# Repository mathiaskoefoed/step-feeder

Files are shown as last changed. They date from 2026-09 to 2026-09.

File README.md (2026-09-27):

# Step Feeder - ESP32 Aquarium Feeder
An ESP32-based automatic aquarium feeder built around the auger screw and food container salvaged from a Juwel SmartFeed 2.0, running on [ESPHome](https://esphome.io/) with full Home Assistant Integration.

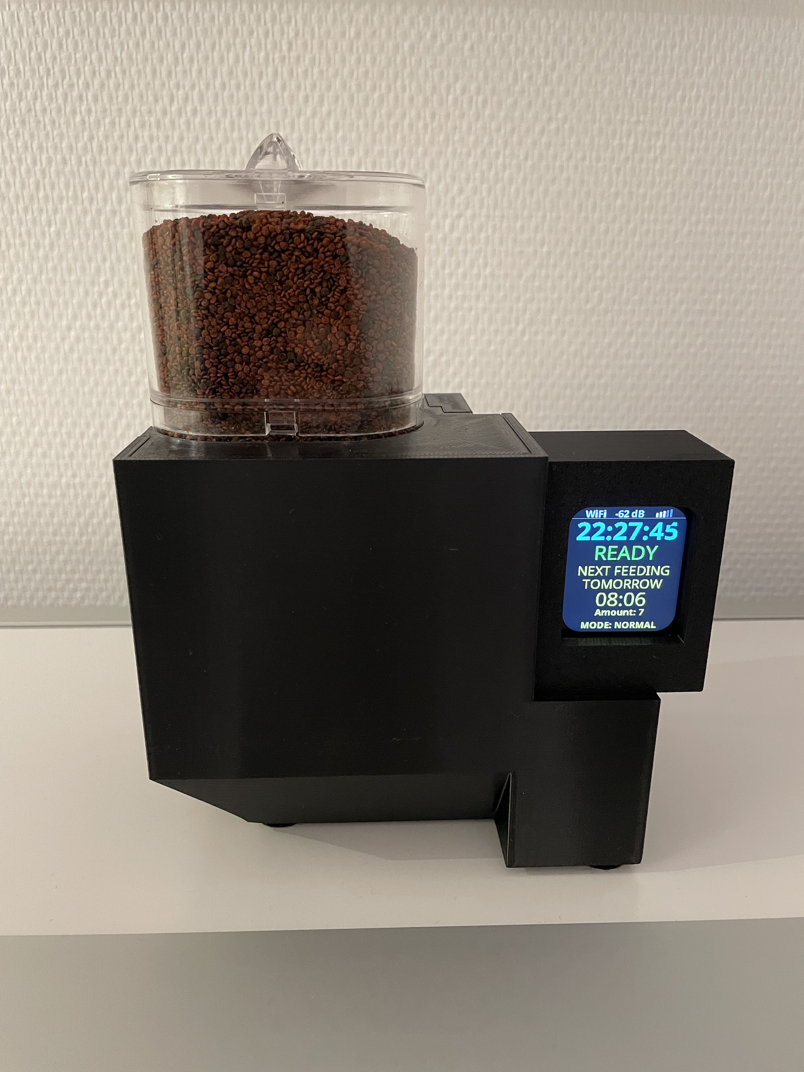
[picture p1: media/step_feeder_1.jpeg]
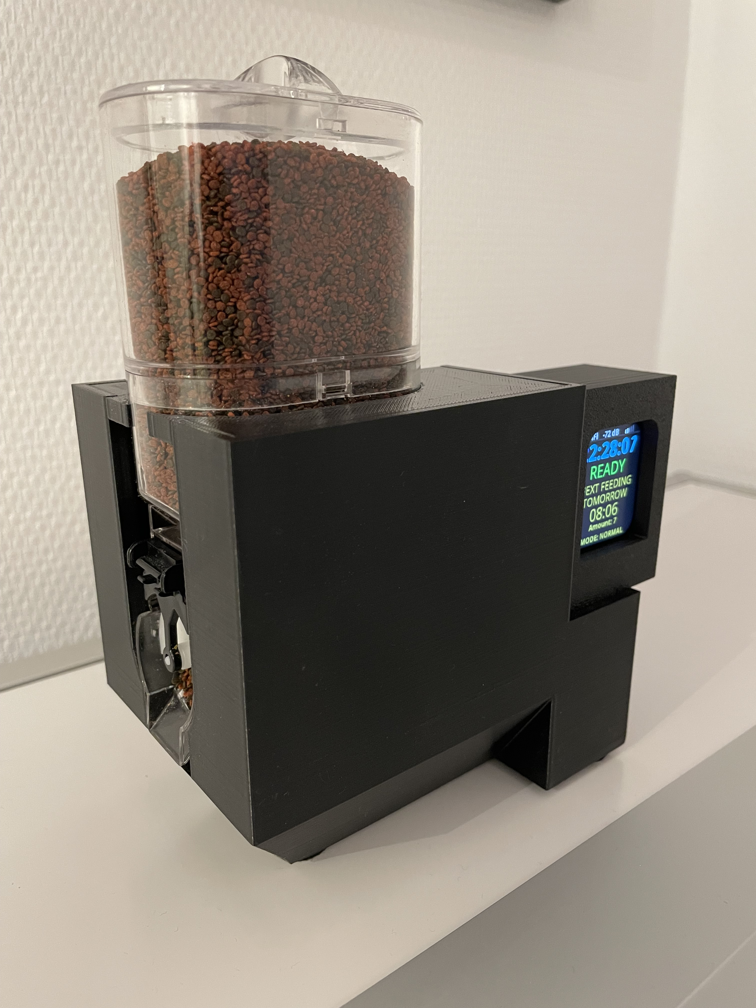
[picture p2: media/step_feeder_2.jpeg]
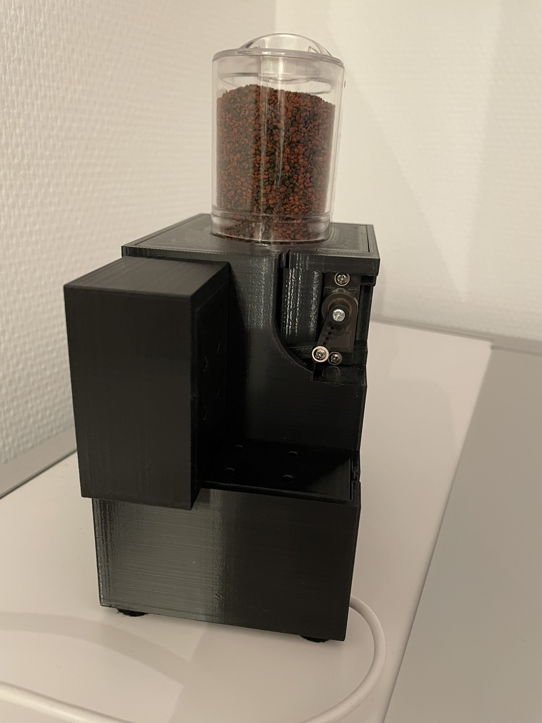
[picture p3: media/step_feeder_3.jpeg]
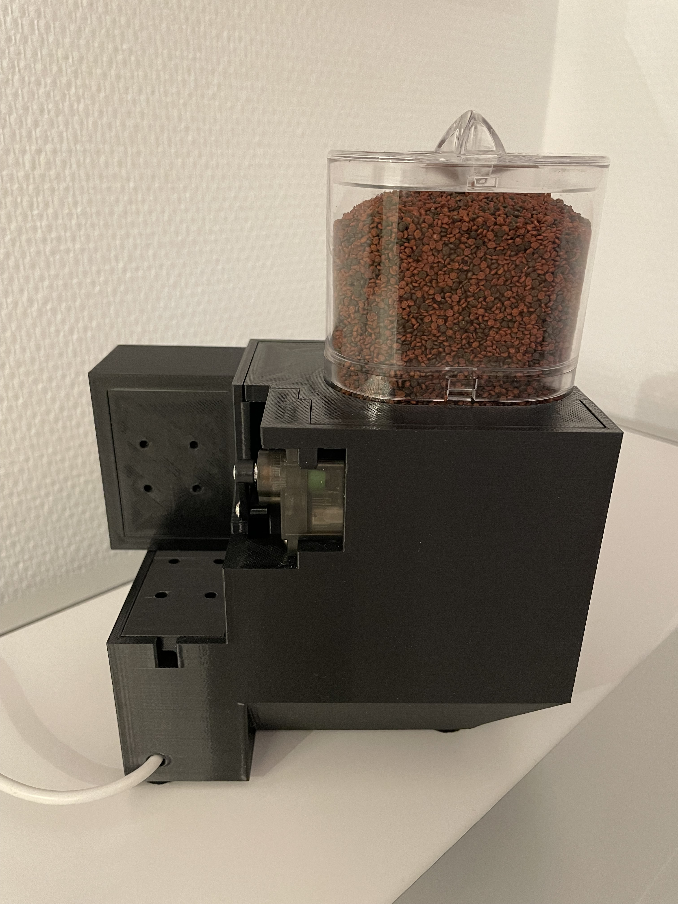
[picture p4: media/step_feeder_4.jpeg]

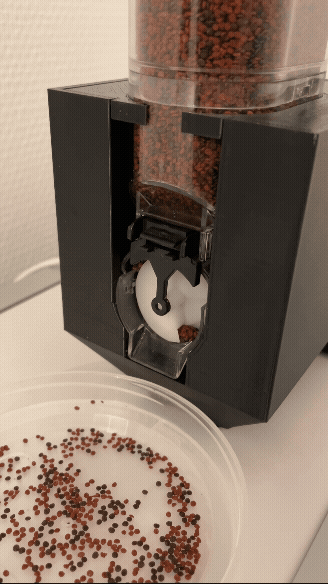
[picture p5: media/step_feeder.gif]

## Table of Contents
- [Features](#features)
- [Add-ons](#add-ons)
- [Hardware](#hardware)
- [Prerequisites](#prerequisites)
- [Build steps](#build-steps)
- [Calibration](#calibration)
- [Home Assistant Integration](#home-assistant-integration)
- [Troubleshooting](#troubleshooting)

## Features

- **Tested** - for 1 year before publishing this feeder
- **Servo-driven auger** - reuses the SmartFeed 2.0's screw mechanism to dispense food in precise portions
- **Onboard display** - ST7789V screen shows the current time, Wifi signal strength, feeder status, next scheduled feeding, amount, and feeding mode.
- **5 independent feeding schedules** - each with its own time, amount, and mode
- **Two feeding modes** - Normal and Extra, with separately tunable servo levels for each
- **Pause mode** - temporarily disable all scheduled feedings without losing the schedule
- **Auto-dim display** - brightness automatically adjusts between day and night levels on a configurable schedule
- **Home Assistant integration** - feed on demand via the `feed_now` action, fires an `esphome.fish_feed` event on every feeding with device/amount/mode/timestamp
- **Feeding history** - tracks total feedings and last/next feeding time, all exposed as Home Assistant entities

## Add-ons
### Funnel
An optional 3D-printed funnel that mounts below the auger outlet to guide the dispensed food directly into the tank opening, reducing spill and keeping food from scattering across the lid.

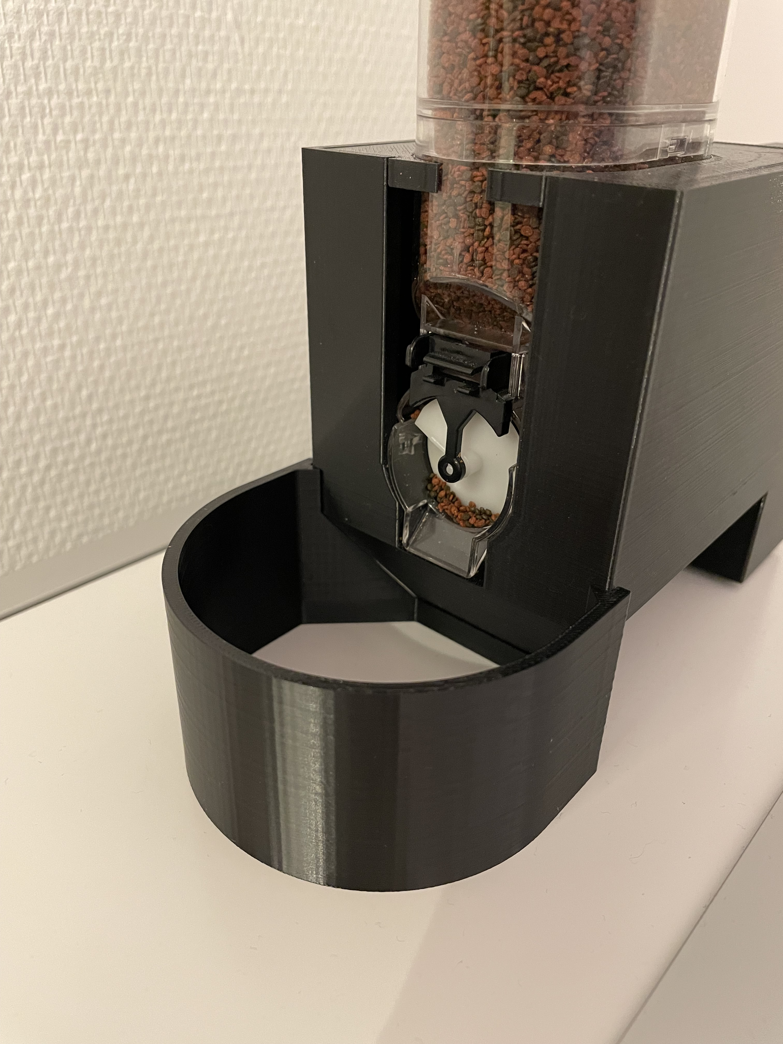
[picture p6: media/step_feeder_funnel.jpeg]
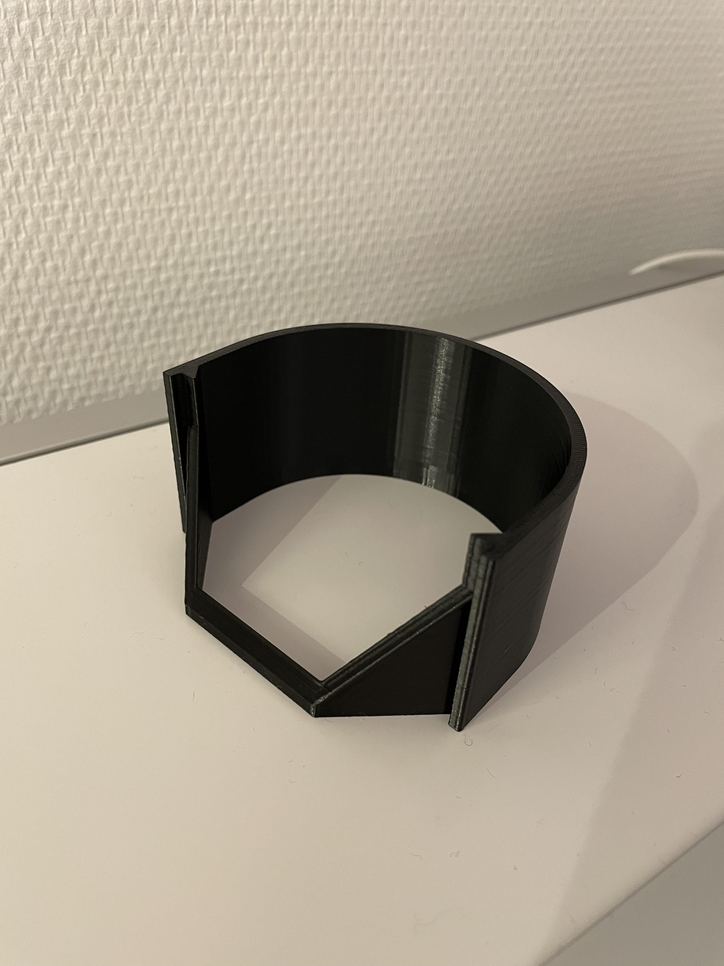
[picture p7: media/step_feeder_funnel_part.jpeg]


## Hardware

- 1 x ESP32S (esp-idf framework) Max size: `26.50 x 52.00mm`
- 1 x ST7789V SPI display (240x280) [Link](https://amzn.eu/d/0fz5knmF)
- 1 x MG90S
- 1 x Juwel SmartFeed 2.0
- 1 x USB cable
- 1 x USB power adapter
- 8 x jumper cable
- [3D Printed Parts](#3d-printed-parts)

## Prerequisites
- **ESPHome 2026.9.0 or newer** - the config uses `min_version: 2026.9.0`, so an older ESPHome install will refuse to compile it.
- **A `secrets.yaml` file** alongside the config, containing your WiFi credentials:
```yaml
wifi_ssid: "your-wifi-name"
wifi_password: "your-wifi-password"
```
- Multiple language variants of the config may exist (`step-feeder-(lang).yaml`). To create your own translation, copy the file and translate the `display_*` and entity-name substitutions at the top.

## Build steps

1. **Flash the step-feeder-(lang).yaml file.** Key settings to adjust in substitutions if needed:

| Setting | Purpose | Default |
|---|---|---|
| `name` | Internal device name (used in hostname etc.) | step-feeder |
| `friendly_name` | Friendly name shown in Home Assistant | Step Feeder |
| `timezone` | Your timezone (used for feeding schedule) | File specific |
| `servo_pin` | GPIO driving the feeding servo | GPIO18 |
| `servo_min_level` | Minimum PWM level for the servo | 2.5% |
| `servo_max_level` | Maximum PWM level for the servo | 24.5% |
| `initial_normal_level` | Default servo level for "normal" feed mode | 18 |
| `initial_extra_level` | Default servo level for "extra" feed mode | 28 |
| `initial_stop_level` | Servo level when stopped/idle | 5 |
| `display_scl_pin` | Display SPI clock pin (SCL/CLK) | GPIO14 |
| `display_sda_pin` | Display SPI data pin (SDA/MOSI) | GPIO23 |
| `display_res_pin` | Display reset pin | GPIO4 |
| `display_dc_pin` | Display data/command pin | GPIO26 |
| `display_cs_pin` | Display chip-select pin | GPIO27 |
| `display_blk_pin` | Display backlight pin | GPIO16 |

2. **Disassemble the Juwel SmartFeed 2.0** and set aside the parts shown below (all screws) - the food container, auger screw, and the 4 screws that originally secured the container to the housing.

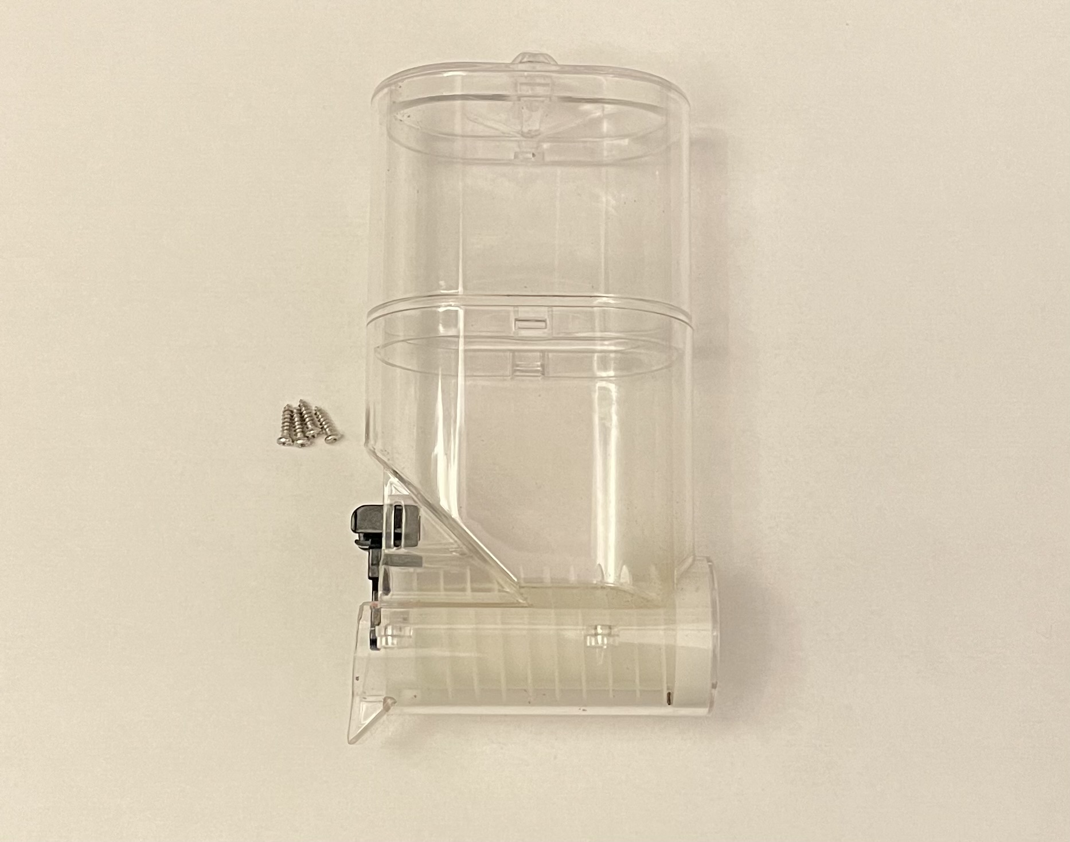
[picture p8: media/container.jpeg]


3. **Mount the food container** to the 3D-printed base using the original 4 screws. The 3D-printed auger screw gear must be inserted into the container **before** the container is screwed down - it can't be added afterward.

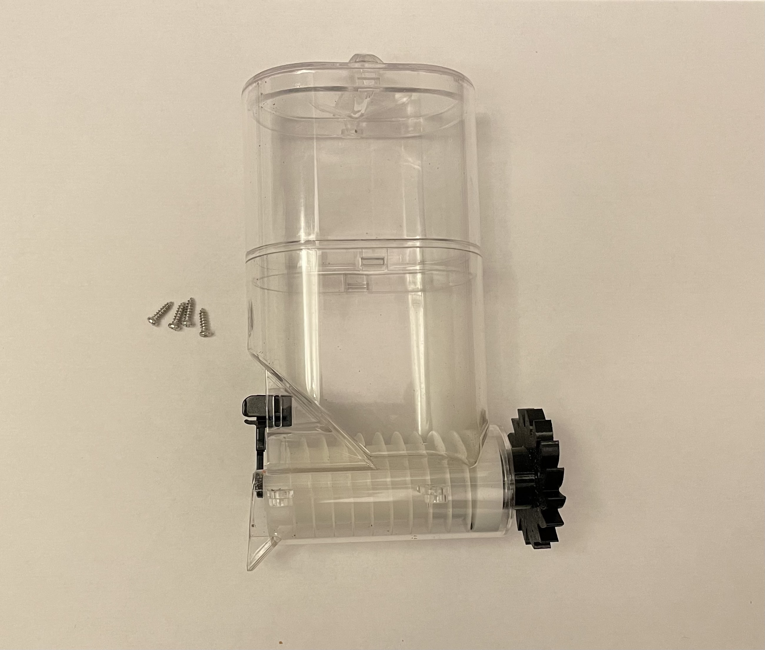
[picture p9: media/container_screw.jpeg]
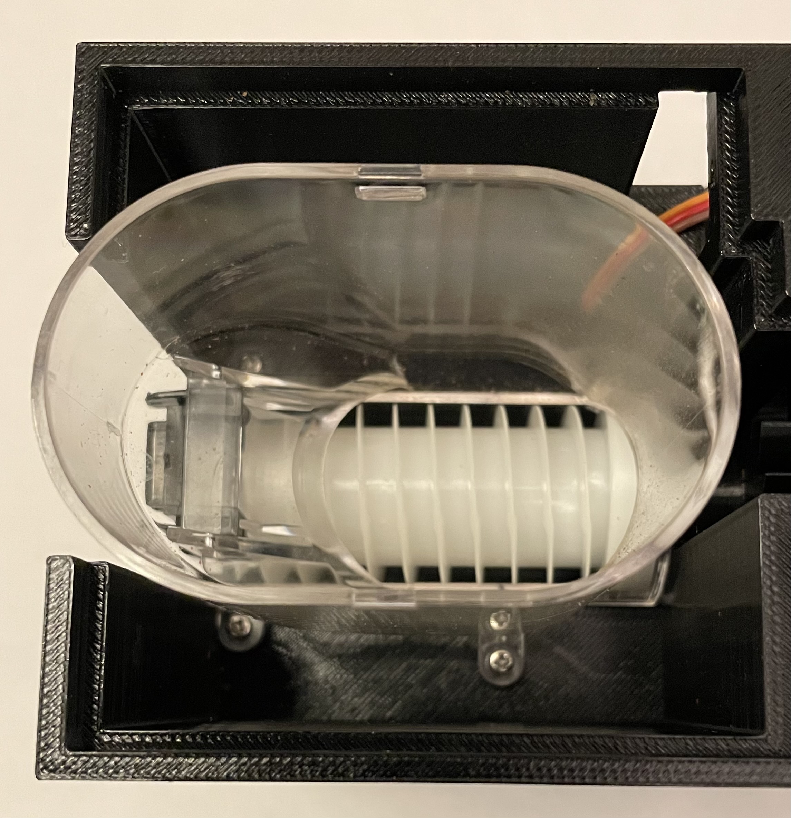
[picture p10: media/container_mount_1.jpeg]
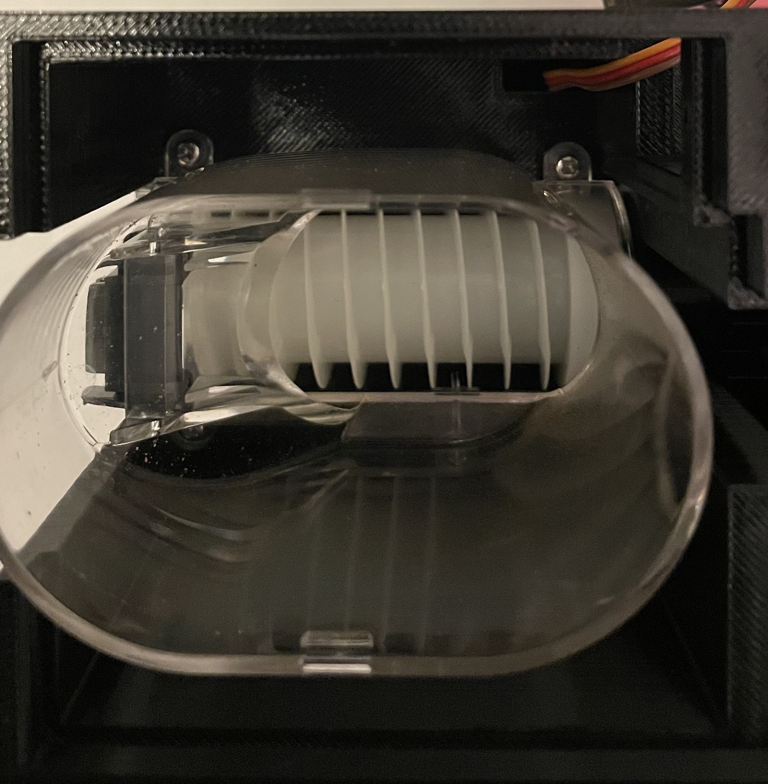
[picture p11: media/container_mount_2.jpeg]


4. **Mount the MG90S servo** using its supplied screws, and route the servo cable through to the compartment where the ESP32 will sit.

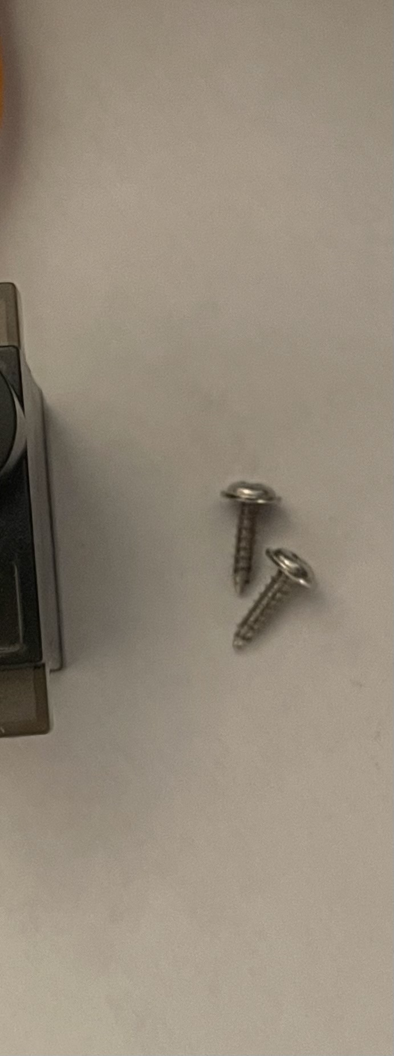
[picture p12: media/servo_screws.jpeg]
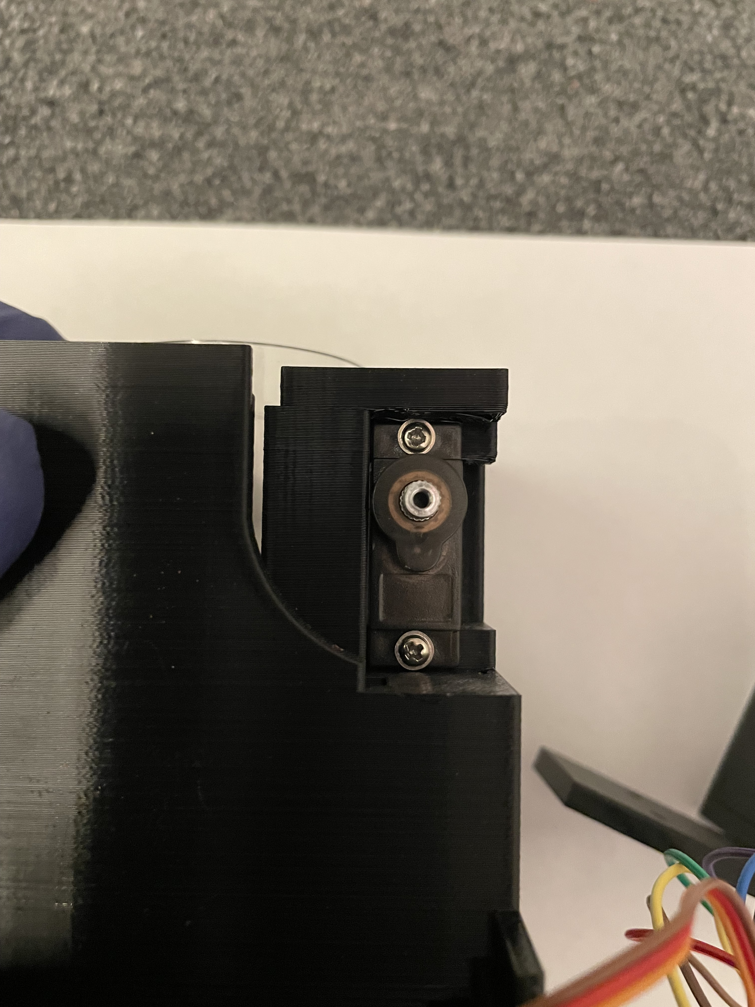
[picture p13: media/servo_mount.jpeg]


5. **Assemble the display**: mount the display to its 3D-printed base with 4 screws, connect the wiring, then feed the cable through the cable hole and attach the display cover. Note which jumper wire color corresponds to which pin - you'll need this when wiring up the ESP32.

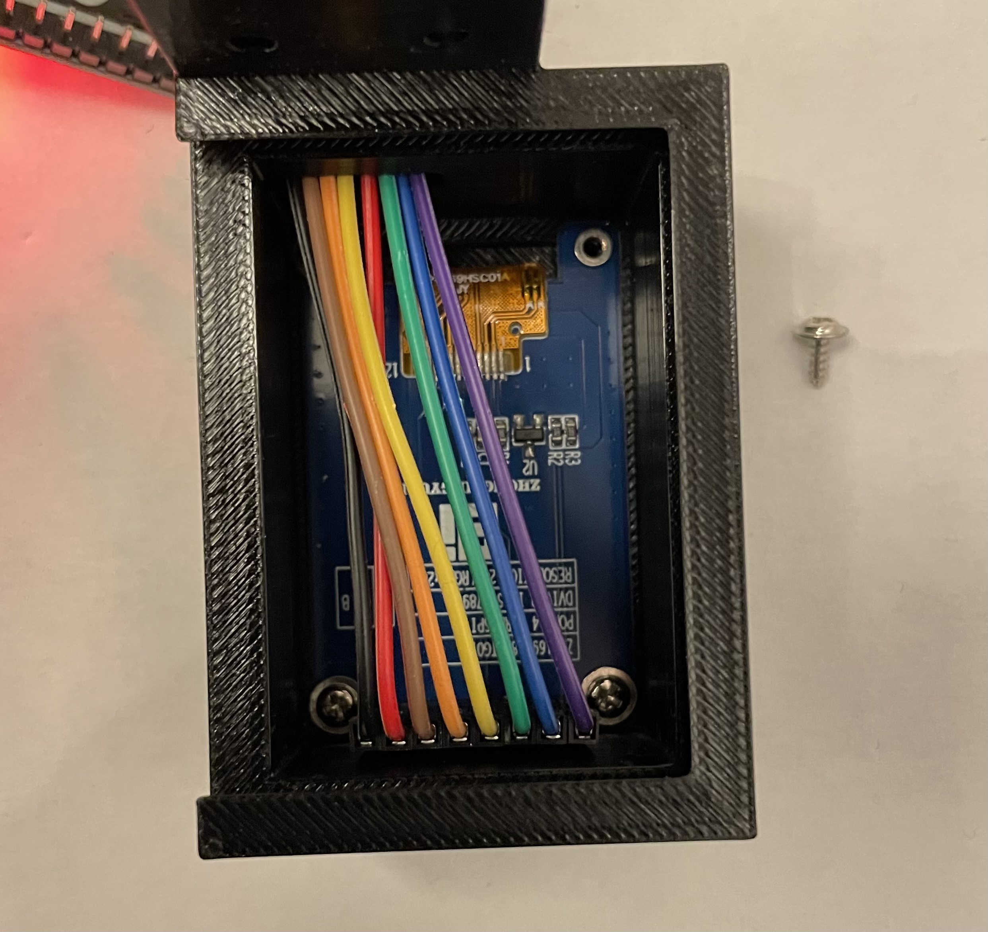
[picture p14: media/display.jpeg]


6. **Route the power cable through the hole and secure it with a zip tie.** 

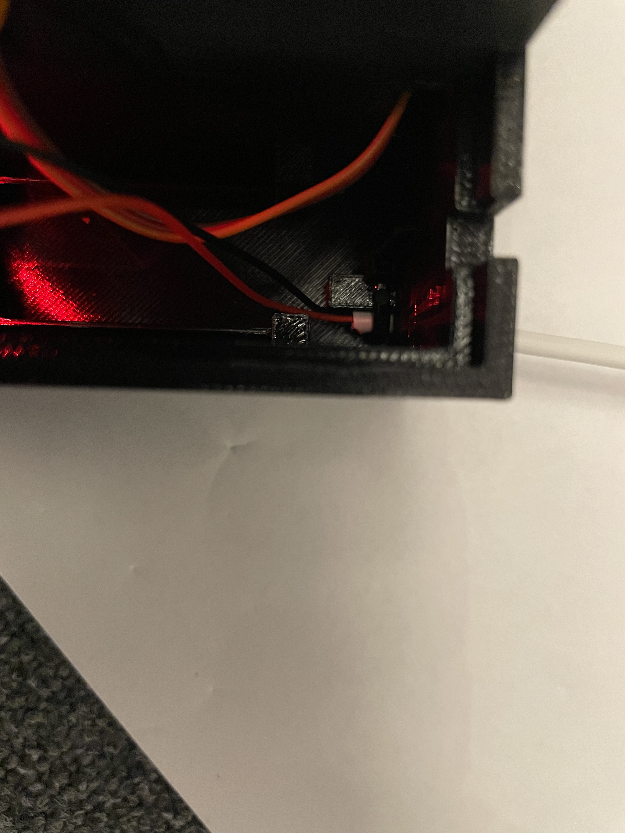
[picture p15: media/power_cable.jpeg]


7. **Wire the ESP32** to the servo, display, and backlight according to the pin table above, using the jumper-wire color mapping from step 5. Twist the positive and ground wires together and secure them with heat shrink, as shown in the picture.

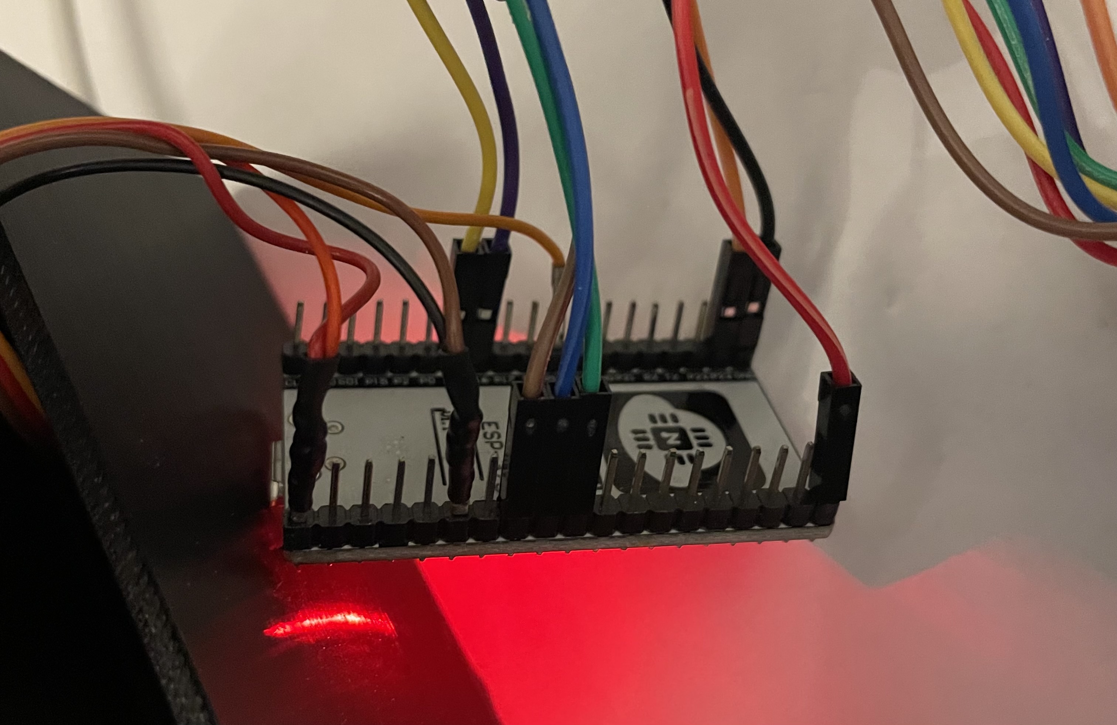
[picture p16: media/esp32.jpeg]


8. Drill an hole thru the original servo arm like this:

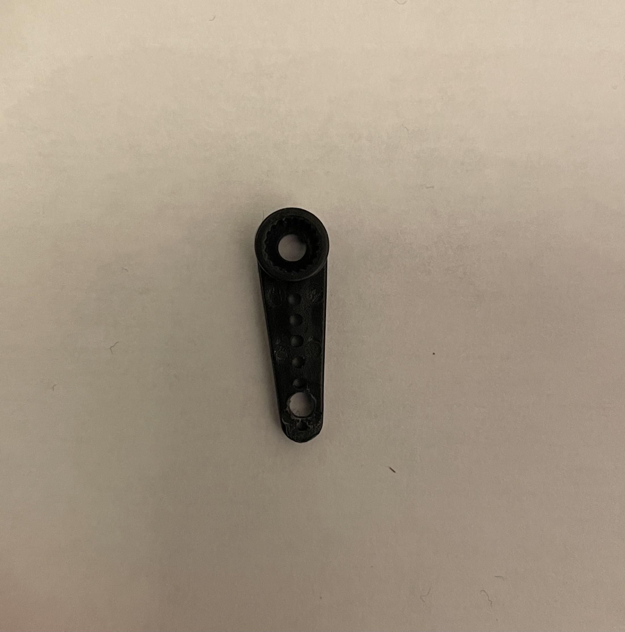
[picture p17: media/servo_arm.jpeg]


9. **Connect ESP32 to Home Assistant** and run 1 feed using the `feed_now` call

10. **Mount the servo arm** at this precies angle like in picture.

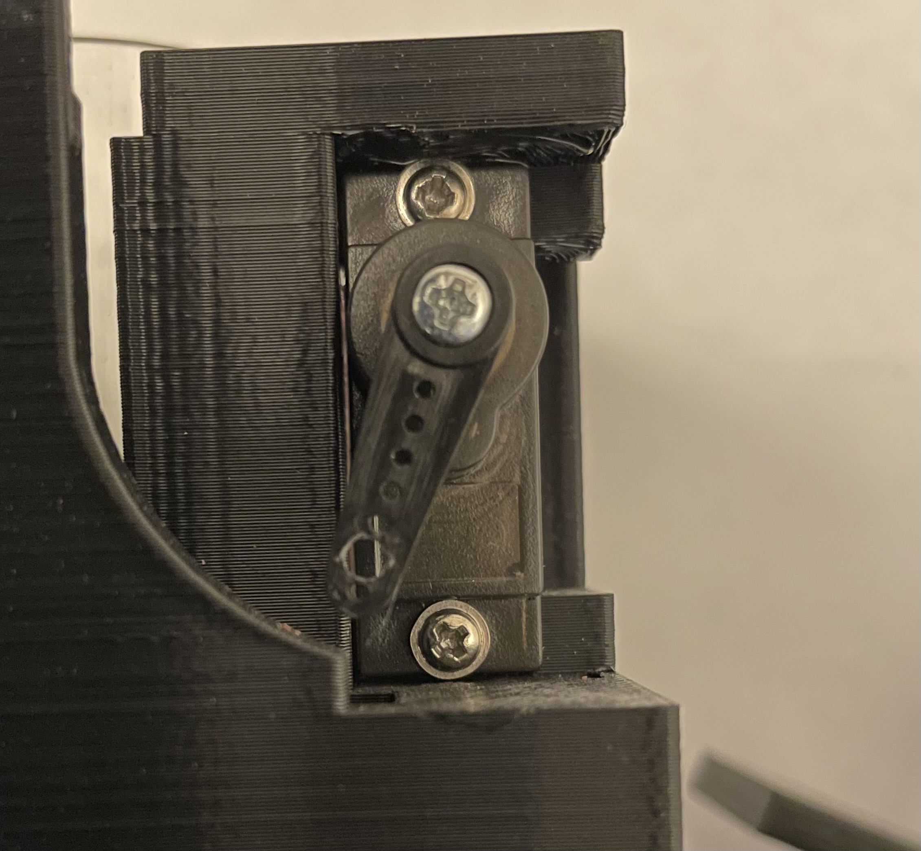
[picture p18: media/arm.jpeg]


11. **Mount the arm with 1 screw.**

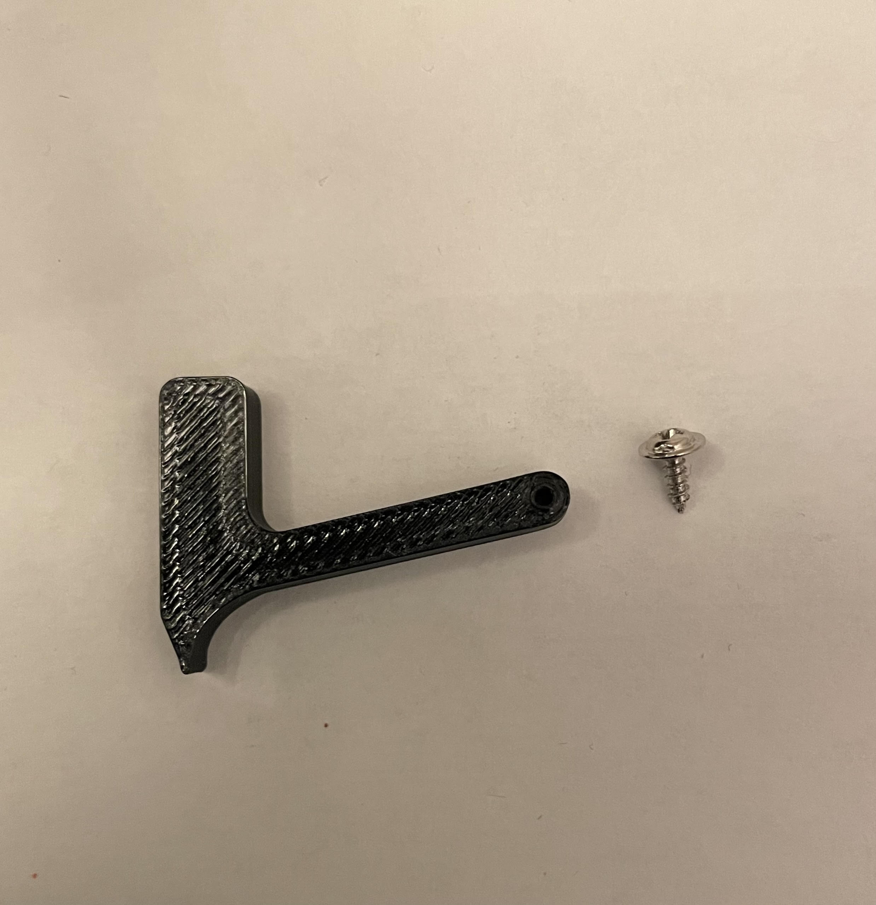
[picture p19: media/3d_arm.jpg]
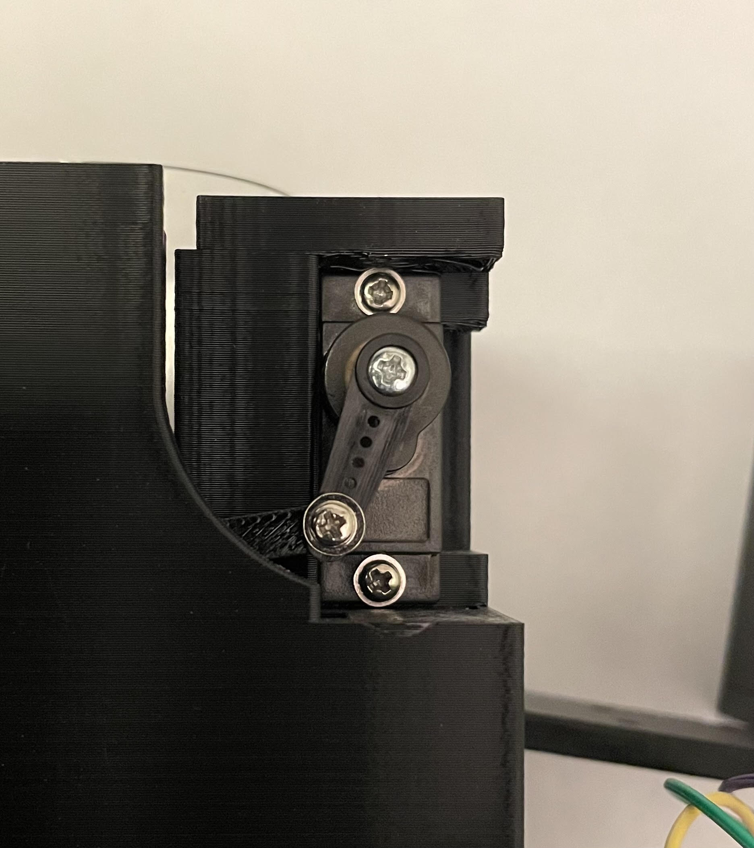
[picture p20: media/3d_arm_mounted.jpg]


## Calibration
The servo levels may need to be tuned after assembly but the default values should work.
1. In Home Assistant, use the **Servo Control** number entity to manually jog the servo to find the current arm level where the auger turns exactly one dispensing cycle.
2. **Normal Level** - set this to the servo level that advances the auger by one tooth.
3. **Extra Level** - set this to the servo level that advances the auger by two teeth.
4. **Stop Level** - set this to the servo level that returns the mechanism to its rest position.

## Home Assistant Integration
### Actions:

| Action | Purpose |
|---|---|
| `esphome.<name>_feed_now` | Trigger an immediate feeding. Parameters: `amount` (int), `mode` (`NORMAL` or `EXTRA`), `override_pause_mode` (bool - feed even if Pause mode is on) |
| `esphome.<name>_reset_total_feed` | Reset the total feedings counter back to 0 |

Example call:
```yaml
action: esphome.step_feeder_feed_now
data:
  amount: 10
  mode: "NORMAL"
  override_pause_mode: false
```
Every feeding also fires an `esphome.fish_feed` event containing `device`,`amount`,`mode`,and `timestamp` data, which you can use in automations.

## 3D Printed Parts
Recommended to use **PETG** for all parts for long term durability.

## Troubleshooting
**Display colors are inverted** - Some ST7789V panels require `invert_colors: false` instead of the default `true`. If the display colors appear inverted, try changing this setting.

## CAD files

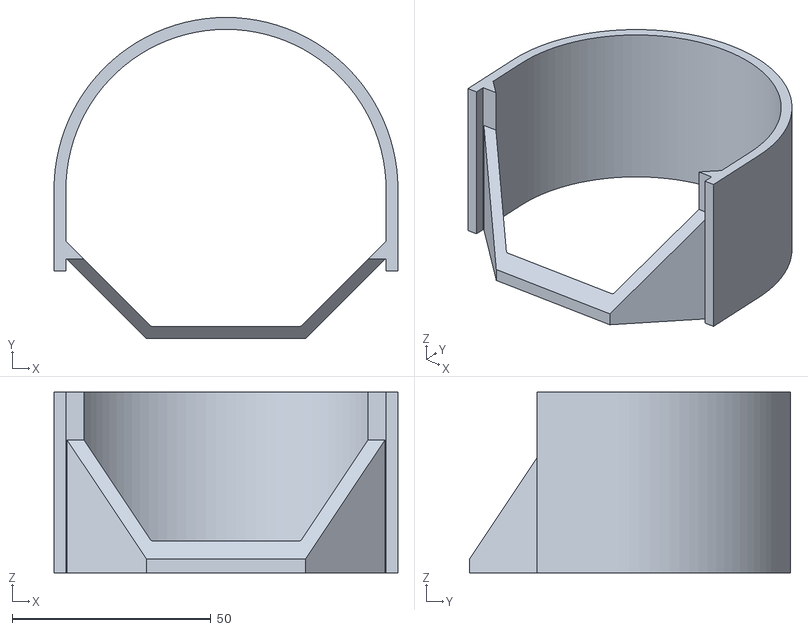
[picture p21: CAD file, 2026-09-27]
stl/step-feeder-funnel.stl
86.5 x 80.8 x 45.5

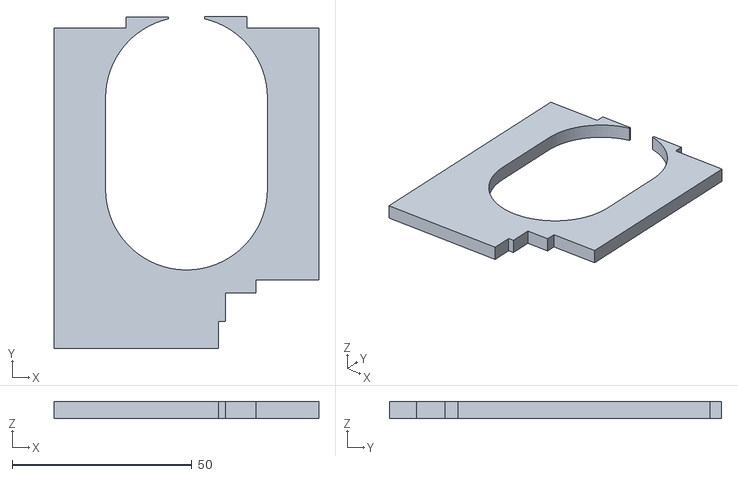
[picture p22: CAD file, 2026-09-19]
stl/step-feeder-base-top-cover.stl
73.7 x 92.3 x 4.80

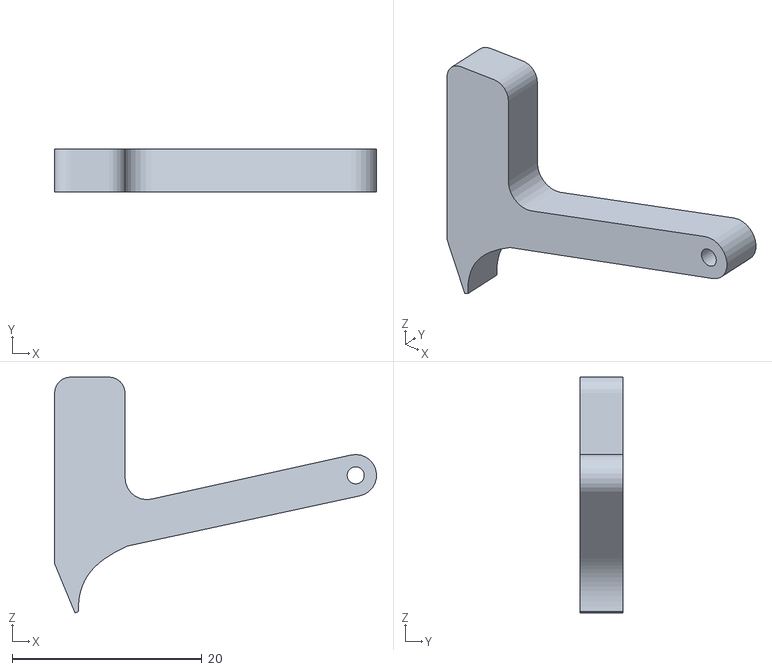
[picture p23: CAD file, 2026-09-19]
stl/step-feeder-arm.stl
33.9 x 4.50 x 24.9

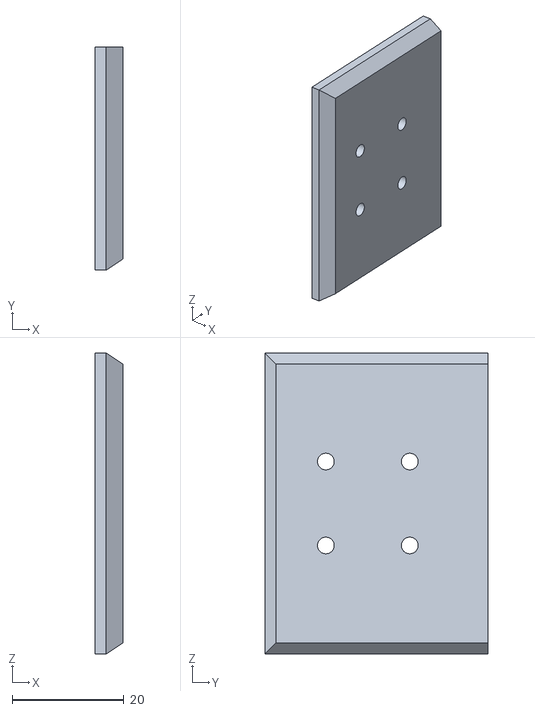
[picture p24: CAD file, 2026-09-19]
stl/step-feeder-display-base-cover.stl
5.00 x 39.9 x 53.8

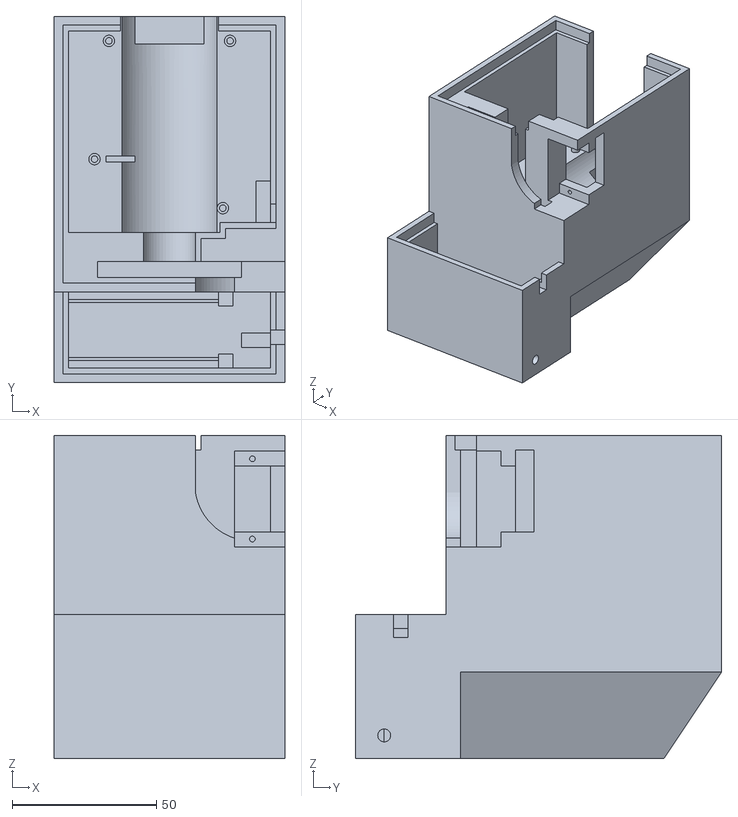
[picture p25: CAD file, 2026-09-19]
stl/step-feeder-base.stl
80.0 x 127.0 x 112.0

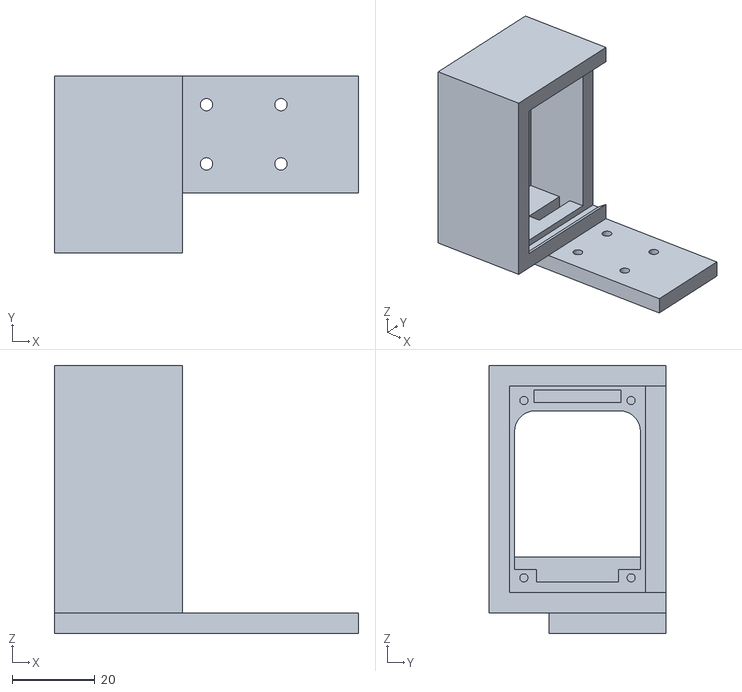
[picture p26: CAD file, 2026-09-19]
stl/step-feeder-display-base.stl
73.7 x 43.0 x 65.0

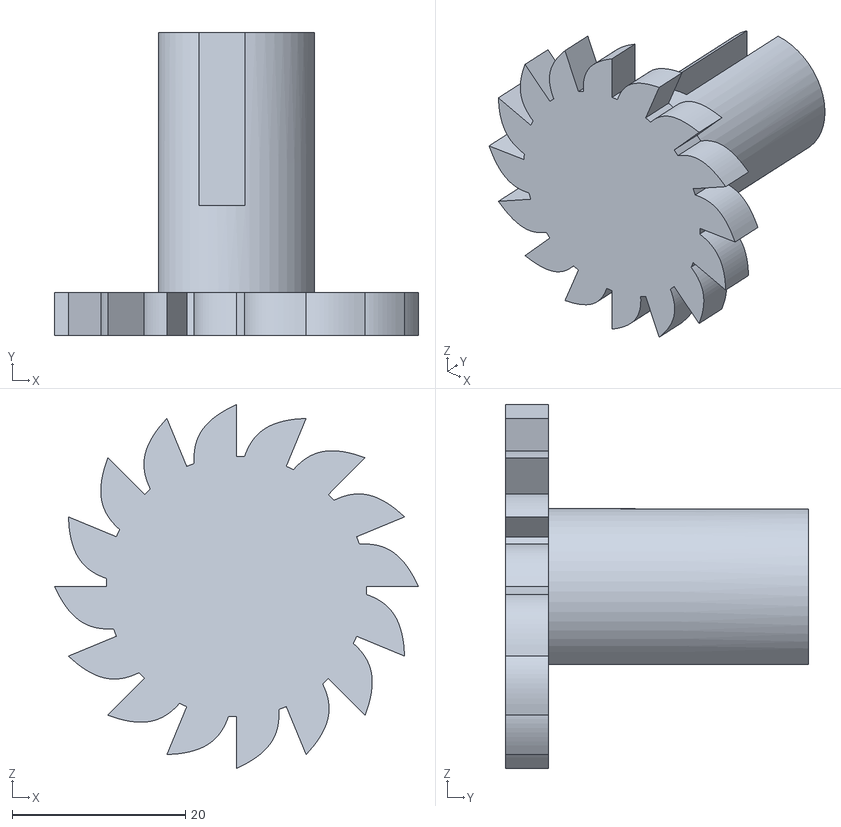
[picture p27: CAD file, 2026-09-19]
stl/step-feeder-screw.stl
42.0 x 35.0 x 42.0

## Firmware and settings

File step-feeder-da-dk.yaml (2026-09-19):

################################
#        CONFIGURATION         #
################################

substitutions:

  ##############################
  #           DEVICE           #
  ##############################
  name: step-feeder
  friendly_name: Step Feeder
  timezone: Europe/Copenhagen


  ##############################
  #           SERVO            #
  ##############################
  servo_pin: GPIO18
  servo_min_level: 2.5%
  servo_max_level: 24.5%
  initial_normal_level: 18
  initial_extra_level: 28
  initial_stop_level: 5


  ##############################
  #          DISPLAY           #
  ##############################
  display_scl_pin: GPIO14
  display_sda_pin: GPIO23
  display_res_pin: GPIO4
  display_dc_pin: GPIO26
  display_cs_pin: GPIO27
  display_blk_pin: GPIO16


  ##############################
  #        DISPLAY TEXT        #
  ##############################
  display_sunday: "SØNDAG"
  display_monday: "MANDAG"
  display_tuesday: "TIRSDAG"
  display_wednesday: "ONSDAG"
  display_thursday: "TORSDAG"
  display_friday: "FREDAG"
  display_saturday: "LØRDAG"

  display_ready: "KLAR"
  display_pause: "PAUSE"
  display_feeding: "FODRER"
  display_next_feeding: "NÆSTE FODRING"
  display_today: "I DAG"
  display_tomorrow: "I MORGEN"
  display_mode: "MODE"
  display_amount: "Mængde"
  display_wifi: "WiFi"


  ##############################
  #        ENTITY NAMES        #
  ##############################
  feed_time_1: "Fodring Tid 1"
  feed_mode_1: "Foder Mode 1"
  feed_amount_1: "Foder Mængde 1"
  feed_time_1_enabled: "Fodring Tid 1 Aktiv"

  feed_time_2: "Fodring Tid 2"
  feed_mode_2: "Foder Mode 2"
  feed_amount_2: "Foder Mængde 2"
  feed_time_2_enabled: "Fodring Tid 2 Aktiv"

  feed_time_3: "Fodring Tid 3"
  feed_mode_3: "Foder Mode 3"
  feed_amount_3: "Foder Mængde 3"
  feed_time_3_enabled: "Fodring Tid 3 Aktiv"

  feed_time_4: "Fodring Tid 4"
  feed_mode_4: "Foder Mode 4"
  feed_amount_4: "Foder Mængde 4"
  feed_time_4_enabled: "Fodring Tid 4 Aktiv"

  feed_time_5: "Fodring Tid 5"
  feed_mode_5: "Foder Mode 5"
  feed_amount_5: "Foder Mængde 5"
  feed_time_5_enabled: "Fodring Tid 5 Aktiv"

  feed_sunday: "Fodring Søndag"
  feed_monday: "Fodring Mandag"
  feed_tuesday: "Fodring Tirsdag"
  feed_wednesday: "Fodring Onsdag"
  feed_thursday: "Fodring Torsdag"
  feed_friday: "Fodring Fredag"
  feed_saturday: "Fodring Lørdag"

  last_feed: "Sidste Fodring"
  next_feed: "Næste Fodring"

  auto_dim: "Auto Dim Skærm"
  screen_brightness: "Skærm Lysstyrke"
  day_brightness: "Dag Lysstyrke"
  night_brightness: "Nat Lysstyrke"
  night_start: "Nat Start"
  night_end: "Nat Slut"

  running: "Køre"
  total_feed: "Total Fodringer"
  wifi_signal: "WiFi Signal"
  uptime: "Oppe Tid"
  restart: "Restart ESP"
  reset: "Reset"

  mode_normal: "NORMAL"
  mode_extra: "EXTRA"
  mode_pause: "Pause Fodring"

  servo_control: "Servo Control"
  normal_level: "Normal Level"
  extra_level: "Extra Level"
  stop_level: "Stop Level"

################################
#           ESPHOME            #
################################

esphome:
  name: ${name}
  friendly_name: ${friendly_name}
  min_version: 2026.9.0
  name_add_mac_suffix: false

  on_boot:
    priority: -100
    then:
      - lambda: 'id(feeding) = false;'

      - lambda: 'id(total_feed).publish_state(id(total_feeds));'

      - servo.write: 
          id: my_servo
          level: !lambda 'return id(stop_level).state / 100.0;'

      - delay: 500ms
      - servo.detach: my_servo
      - script.execute: update_next_feed_time
  on_shutdown: 
    then:
      - servo.detach: my_servo

################################
#            ESP32             #
################################

esp32:
  variant: esp32

  framework:
    type: esp-idf

    advanced: 
      minimum_chip_revision: "3.1"
      sram1_as_iram: true

################################
#            SYSTEM            #
################################

logger:
  baud_rate: 0

api:
  reboot_timeout: 0s
  listen_backlog: 1
  max_connections: 2
  max_send_queue: 4
  batch_delay: 50ms
  actions: 
    - action: feed_now
      variables:
        amount: int
        mode: string
        override_pause_mode: bool

      then:
        - if:
            condition:
              lambda: 'return (!id(pause_mode).state || override_pause_mode) && !id(feeding);'
            then:
              - script.execute:
                  id: feed_fish
                  amount: !lambda 'return amount;'
                  mode: !lambda 'return mode;'

    - action: reset_total_feed
      then:
        - lambda: |-
            id(total_feeds) = 0;
            id(total_feed).publish_state(id(total_feeds));

ota:
- platform: esphome


################################
#             WIFI             #
################################

wifi:
  ssid: !secret wifi_ssid
  password: !secret wifi_password

  reboot_timeout: 0s
  power_save_mode: NONE
  fast_connect: true
  output_power: 18
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
